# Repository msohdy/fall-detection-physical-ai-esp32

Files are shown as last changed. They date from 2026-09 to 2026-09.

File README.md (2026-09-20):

# Fall Detection & Alert System

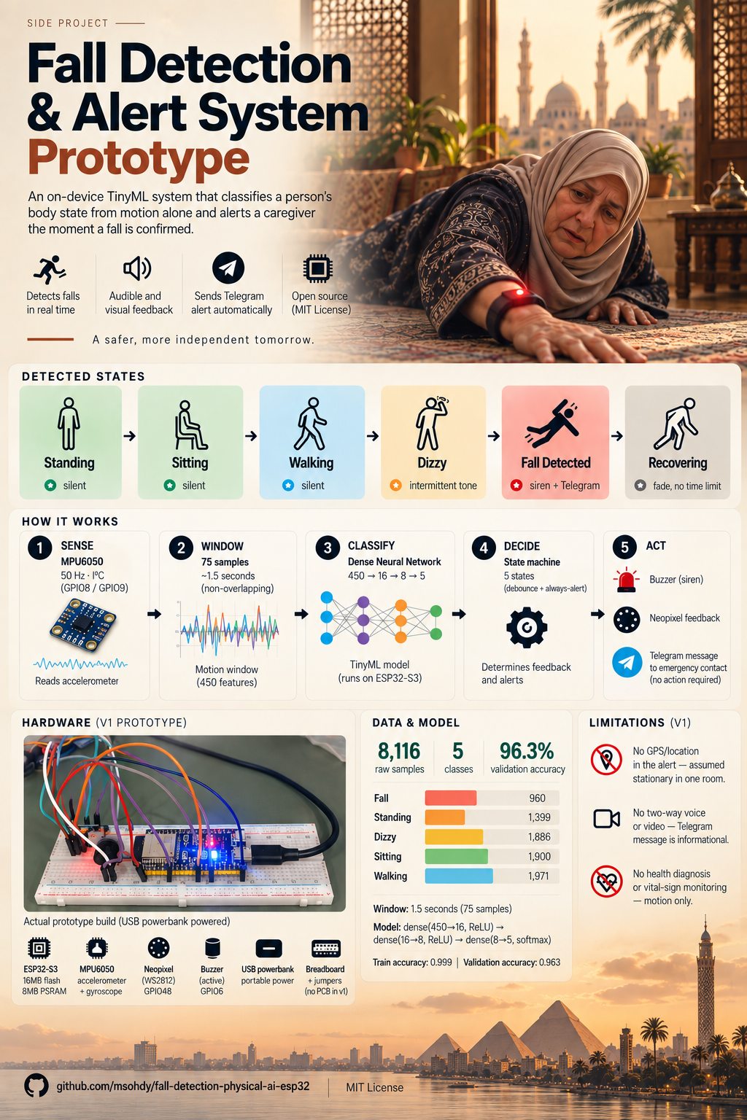
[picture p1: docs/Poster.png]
Fall Detection & Alert System poster


An ESP32-S3 wearable/room device that classifies body state (standing, sitting, walking, dizzy, fall) from MPU6050 motion data using an on-device TinyML model, gives silent per-state Neopixel feedback, sounds a buzzer for concerning states, and sends a Telegram alert to an emergency contact when a fall is confirmed.

**Status:** Phase 6 complete — Phase 7: Testing & Validation in progress. (Phase 6 closed with one small item carried forward: a clean final untethered/battery confirmation run, folded into Phase 7's checklist.)

> This README is being filled in phase by phase as the project is built — see `CLAUDE.md` and `docs/TASKS.md`. Sections below will fill in as each phase completes.

**Repo:** [github.com/msohdy/fall-detection-physical-ai-esp32](https://github.com/msohdy/fall-detection-physical-ai-esp32) · **Project board:** [Fall Detection Build Roadmap](https://github.com/users/msohdy/projects/3)

## Overview

**Problem.** A person living or working alone has no automatic way to signal a fall. Manual alerting (pressing a button, calling out) fails exactly when someone is unconscious or too disoriented to act.

**Goals**

- Classify body state in real time from IMU data: standing, sitting, walking, dizzy, fall.
- Give silent, glanceable feedback (Neopixel color) for every state, so the device isn't alarming during normal activity.
- Escalate audibly only for concerning states (dizzy, fall) — a caregiver should be able to tell severity apart by sound alone.
- On a confirmed fall, notify a remote emergency contact over Telegram without requiring the fallen person to act.
- Require a sustained, confirmed signal before silencing an alarm, to avoid false-clears from a momentary misread.

**Non-goals (v1)**

- No health diagnosis or vital-sign monitoring — the device infers activity state from motion only.
- No GPS/location in the alert (device is assumed stationary within one home/room).
- No two-way voice or video in the alert — the Telegram message is informational, not a call.

**How the built system differs from the original PRD** (full detail in [Firmware Architecture](#firmware-architecture), [Known Limitations](#known-limitations), and `docs/TASKS.md`):

- No TFLite Micro — inference is a hand-rolled forward pass over a custom-trained dense network (Edge Impulse was dropped entirely; see [Training the Model](#training-the-model)).
- Fall confirmation and alerting is a `FALLEN` → `ALARMED` debounce-then-always-alert design, not the PRD's single-frame trigger — a deliberate product decision made during Phase 6 testing, prioritizing "never suppress a real alert" over "never send an extra one."
- v1 is a handheld breadboard prototype (powered by a USB powerbank), not the wearable or room-mounted form factor the PRD assumed — see [Bill of Materials](#bill-of-materials) and the Wiring section's form-factor note.
- "Zero missed falls" is not yet fully met by the trained model (~11.2% of fall samples still confused with "dizzy") — see [Known Limitations](#known-limitations).

## Bill of Materials

- **ESP32-S3 dev board** — generic ESP32-S3-N16R8 board (16MB flash, 8MB PSRAM). Runs the classifier, state machine, and WiFi/Telegram calls. *Not* the official ESP32-S3-USB-OTG devkit that `platformio.ini`'s board ID technically names — see [Build Log](#build-log--decisions).
- **MPU6050 breakout** — standard I²C accelerometer+gyroscope module. Primary sensor, feeds the windowed IMU data the classifier reads.
- **Neopixel LED** — the board's onboard single WS2812 RGB LED (GPIO48), no external strip used. Silent per-state color feedback.
- **Buzzer** — a 3-pin module that turned out to be **active** with no usable signal pin (see [Wiring](#wiring)), controlled by switching its power via GPIO6. Audible escalation for dizzy/fall states.
- **Power source (v1)** — USB powerbank. Portable power for the handheld breadboard prototype.
- **Breadboard + jumper wires** — standard prototyping breadboard, no PCB in v1.

**Not used in this project** (per the original PRD, reserved for a different/future project): camera, DHT11, IR sensor, ultrasonic sensor, fan/relay, servo motor.

*Specific vendor links aren't included yet — these are generic, widely available parts. Sourcing links can be added here later if useful for reproducing the exact build.*

## Wiring

**Diagram tool:** [Fritzing](https://fritzing.org/) (free, open source, breadboard-style diagrams; switched from an initial Wokwi plan once actually building the diagram).

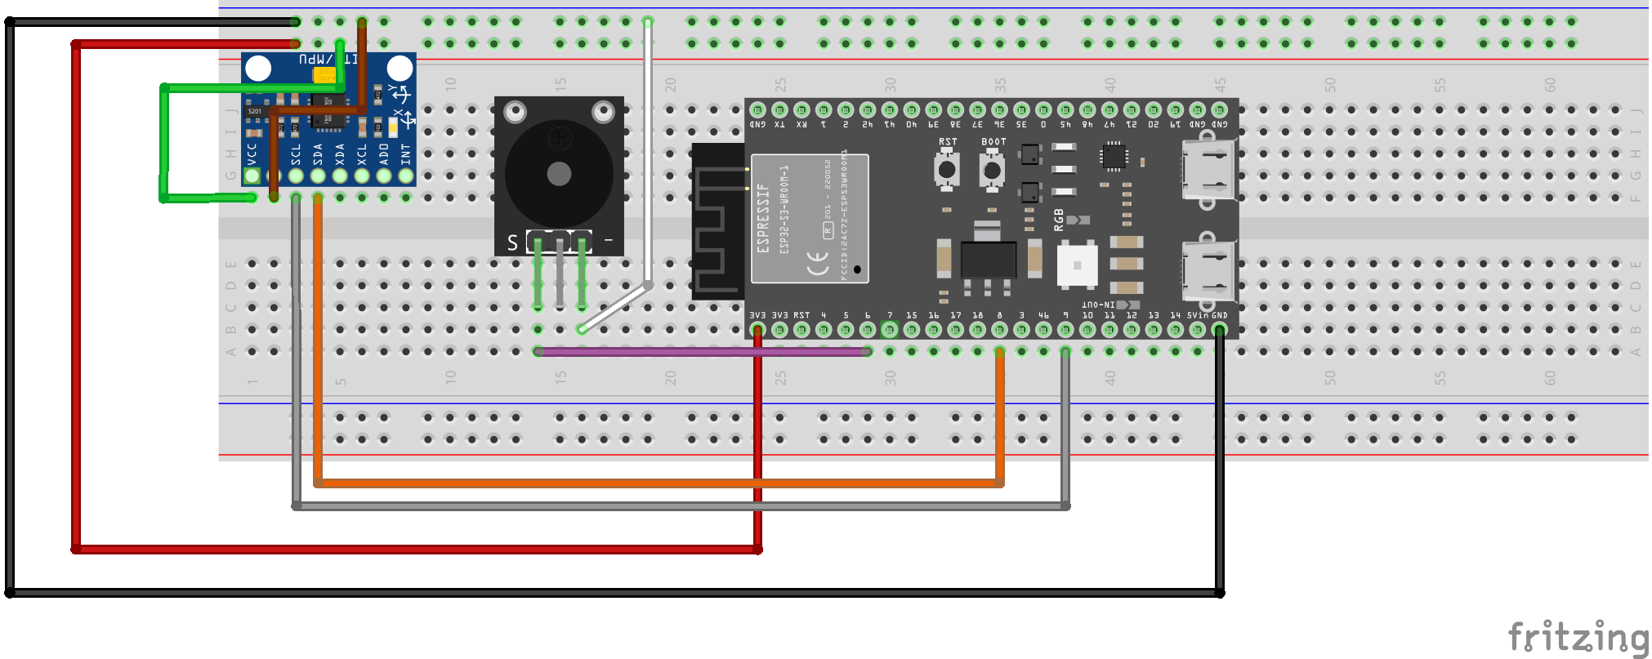
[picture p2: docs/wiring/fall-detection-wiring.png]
Breadboard wiring diagram


Fritzing project source: [`docs/wiring/fall-detection-wiring.fzz`](docs/wiring/fall-detection-wiring.fzz)

**Actual build:**

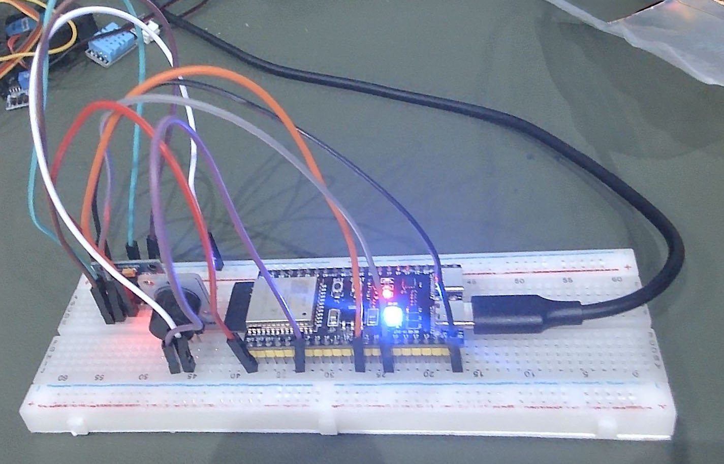
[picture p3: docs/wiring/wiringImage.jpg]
Breadboard photo


**Pin table:**

| Signal | MPU6050 | Neopixel (onboard) | Buzzer (active) |
| --- | --- | --- | --- |
| Power | VCC → 3.3V | onboard, no wiring | + → **GPIO6** (switched power) |
| Ground | GND → GND | onboard | - → GND |
| Data/Signal | SDA → GPIO8 | GPIO48 (onboard) | *(none — see note below)* |
| Clock | SCL → GPIO9 | — | — |

The Neopixel is the board's onboard single WS2812 RGB LED, not an external strip. The buzzer is confirmed **active** with no dedicated signal pin at all — its 3rd pin is unused, and it's controlled by switching power to it directly via GPIO6 (`digitalWrite(HIGH/LOW)`), not `tone()`. See [Build Log / Decisions](#build-log--decisions) for how this was determined.

**Form factor (v1):** breadboard prototype, powered by a USB powerbank — handheld, not worn or room-mounted. No enclosure/form-factor commitment yet; strain relief and wearable-specific concerns are out of scope until a final form factor is chosen.

## Setup

**Firmware toolchain:** [PlatformIO](https://platformio.org/) as a VS Code extension.

- Board: `esp32s3usbotg` in `platformio.ini` (PlatformIO's board ID for Espressif's official ESP32-S3-USB-OTG devkit). The actual hardware is a generic ESP32-S3-N16R8 dev board (confirmed via `esptool flash_id`: ESP32-S3, 16MB quad-I/O flash, 8MB quad PSRAM) — see [Build Log / Decisions](#build-log--decisions).
- Framework: `arduino`
- Confirmed: project builds and uploads over USB (native USB port, shows up as `VID:PID=303A:1001`).

**Before building, set up your own credentials** (the repo never contains real ones):

1. Copy [`include/secrets.h.example`](include/secrets.h.example) to `include/secrets.h` (git-ignored — never commit this file).
2. Fill in `WIFI_SSID` / `WIFI_PASSWORD` for the network the device should join. Note: the ESP32-S3 is **2.4GHz WiFi only** — if using a phone hotspot, make sure it's not set to 5GHz-only (see [Known Limitations](#known-limitations)).
3. Create a Telegram bot via [@BotFather](https://t.me/BotFather) and copy its token into `TELEGRAM_BOT_TOKEN`.
4. Message your new bot once (anything), then visit `https://api.telegram.org/bot<YOUR_TOKEN>/getUpdates` in a browser and copy the numeric `"chat":{"id": ...}` value into `TELEGRAM_CHAT_ID` — not the lookup URL itself, the actual number.

Then build and flash — see [Building & Flashing](#building--flashing) below.

## Data Collection Tooling

**[`tools/serial-data-logger.html`](tools/serial-data-logger.html)** — a self-contained Web Serial page (Chrome/Edge only) for capturing MPU6050 samples to CSV. Built after two Edge Impulse ingestion paths turned out to be dead ends on this setup:

1. `edge-impulse-cli` (for the classic Data Forwarder) failed to install — one dependency needs native compilation via Visual Studio Build Tools, which aren't installed.
2. Edge Impulse Studio's browser-based "Connect a new device" WebSerial flow requires the device firmware to speak Edge Impulse's AT-command protocol — a different thing entirely from plain CSV serial output, and not worth implementing just for data collection.

Connect to the board, log incoming CSV lines to an editable table (delete bad rows individually or in bulk, or reopen an already-saved CSV via **Load CSV**), and export a clean CSV per recording session.

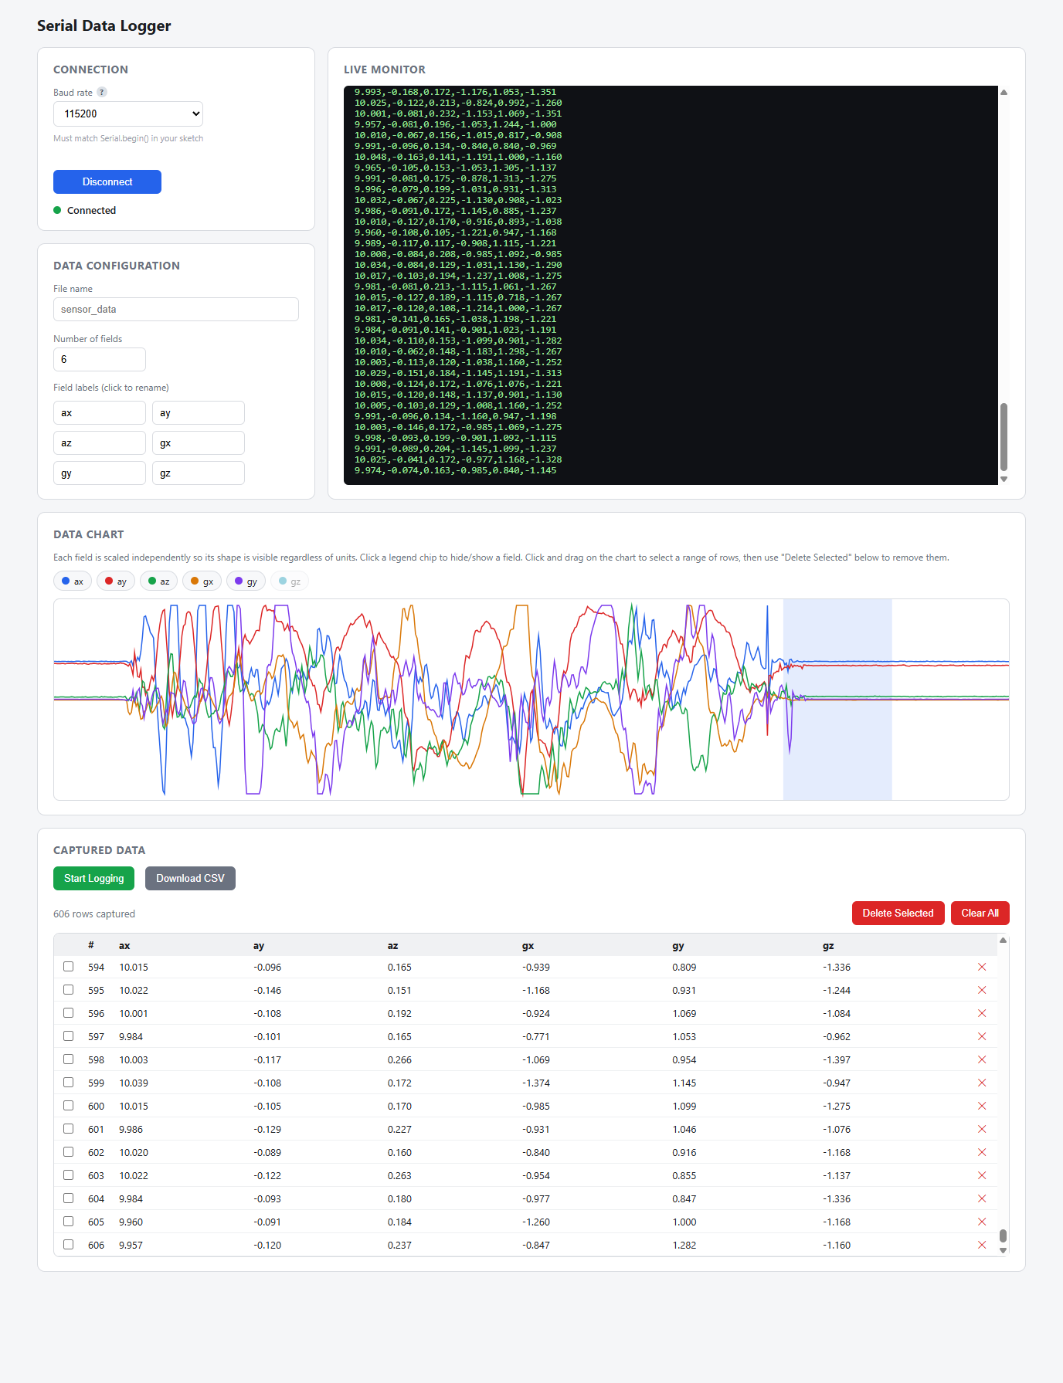
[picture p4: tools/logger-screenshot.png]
Serial Data Logger


See [`tools/README.md`](tools/README.md) for full usage instructions and the data collection + training pipeline diagram.

## Training the Model

Edge Impulse was dropped entirely as the training platform too (not just the data-connection method above) — see [Build Log / Decisions](#build-log--decisions). Instead: **[`tools/tinyml-trainer.html`](tools/tinyml-trainer.html)**, a self-contained TensorFlow.js page that trains a small dense-network classifier client-side and exports a plain C header for firmware.

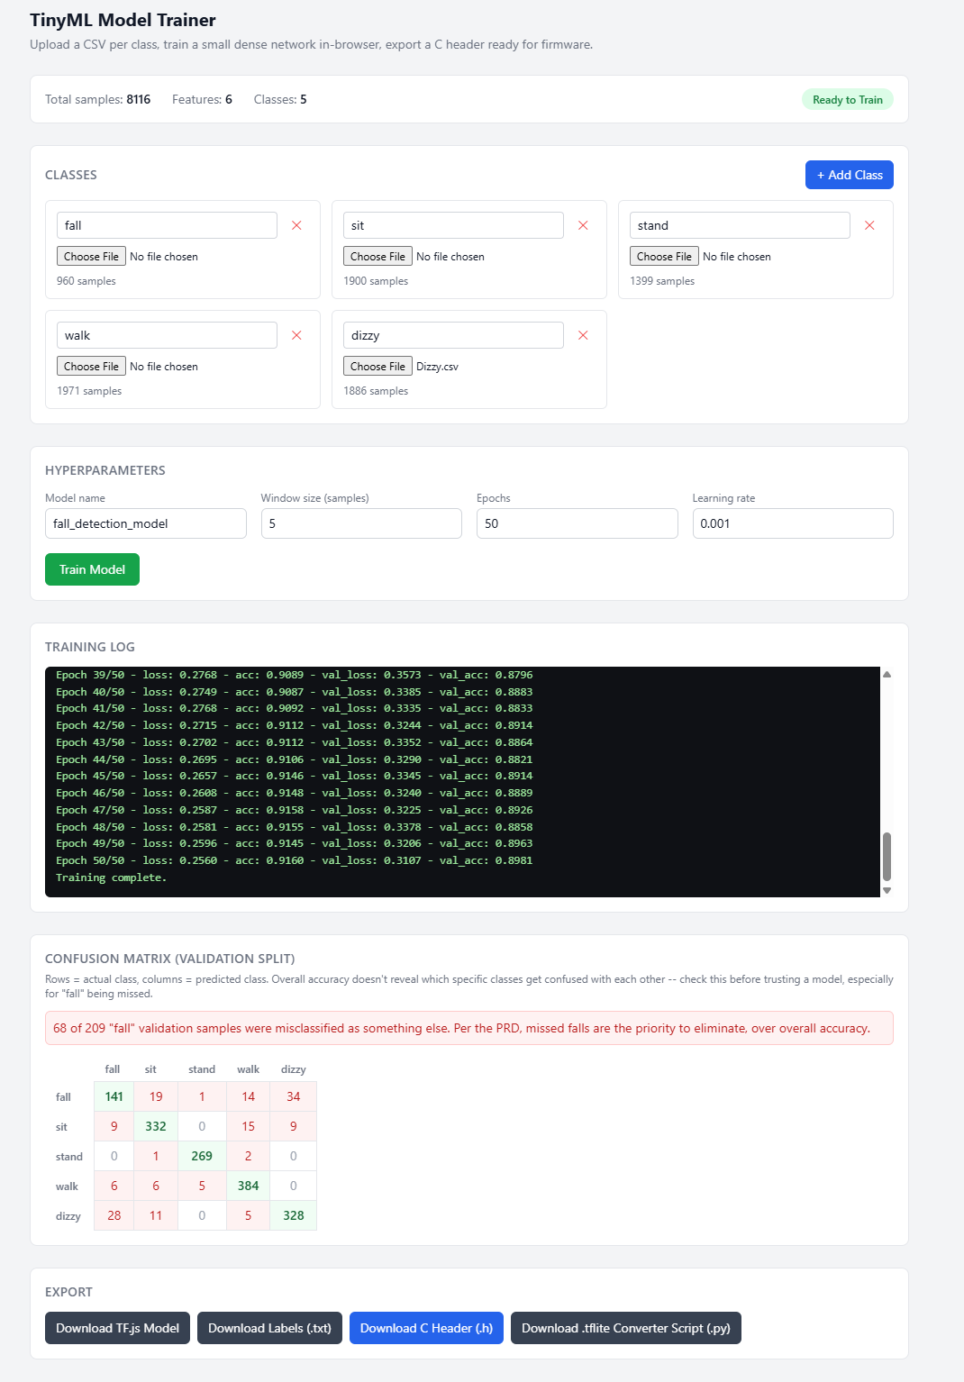
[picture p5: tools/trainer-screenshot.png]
TinyML Model Trainer


**Dataset:** 8116 raw samples across 5 classes (fall 960, sit 1900, stand 1399, walk 1971, dizzy 1886), collected handheld (see Wiring's form-factor note) via `serial-data-logger.html`.

**Model:** `dense(16, relu) → dense(8, relu) → dense(5, softmax)`, trained on windowed raw accel+gyro samples (no DSP/spectral feature extraction). Final: window size 75 samples (~1.5s at 50Hz), 50 epochs, learning rate 0.001, train accuracy 0.999, validation accuracy 0.963.

**Window size mattered a lot.** Started at window=5 (100ms) — far shorter than the PRD's suggested ~1-2s — and it showed:

| Window size | Duration @ 50Hz | Overall val accuracy | Fall samples missed |
| --- | --- | --- | --- |
| 5 | 0.1s | ~0.87 | 68/209 (32.5%) |
| 50 | 1.0s | 0.958 | 39/191 (20.4%) |
| 75 | 1.5s | 0.963 | 23/205 (11.2%) — accepted for v1 |

**Known limitation:** the PRD's "zero missed falls" bar is not fully met — 11.2% of fall validation samples are still confused with "dizzy," which is more likely a data-realism issue (handheld mimicked falls vs. a real worn fall's sharper signature) than something further hyperparameter tuning alone would fix. See [Known Limitations](#known-limitations).

Full model header: [`include/fall_detection_model_data.h`](include/fall_detection_model_data.h). See [`tools/README.md`](tools/README.md) for the trainer's usage instructions and a real bug (a `validationSplit` shuffling gotcha) worth knowing about if you extend this tool.

## Firmware Architecture

**Deviation from the PRD:** no TFLite Micro. Since training moved to a custom in-browser trainer (above) that exports raw float weight/bias arrays instead of a `.tflite` file, the firmware does inference by hand instead of via a TFLite Micro runtime.

| Module | Files | Responsibility |
| --- | --- | --- |
| MPU6050 driver | `mpu6050.h/.cpp` | Raw I2C register reads (same approach as the Phase 4 data-forwarder sketch), scaled to match training data exactly |
| Model inference | `model_inference.h/.cpp` | Hand-rolled `dense(450→16, ReLU) → dense(16→8, ReLU) → dense(8→5) → argmax` forward pass over `fall_detection_model_data.h` |
| Neopixel driver | `neopixel_driver.h/.cpp` | `VisualState` enum; steady colors for standing/sitting/walking/dizzy, non-blocking pulse/fade animation for alarmed/recovering |
| Buzzer driver | `buzzer_driver.h/.cpp` | `BuzzerState` enum; distinct non-blocking on/off beep *patterns* per state (this buzzer can't vary pitch — see Wiring section) |
| State machine | `state_machine.h/.cpp` | NORMAL/DIZZY/FALLEN/ALARMED/RECOVERING transitions, using string comparison against model labels (not hardcoded indices) |
| Telegram | `telegram.h/.cpp` | HTTPS GET to the Bot API, run entirely on its own FreeRTOS task (see below) so a slow/retrying send can never stall sensor sampling or classification |

**Classification runs on a fresh, non-overlapping ~1.5s window per cycle**, not continuously — see [Known Limitations](#known-limitations) for why continuous classification made false alarms dramatically worse.

**Fall confirmation and alerting (deviation from the original single-fall-triggers-alert design, decided during Phase 6 testing):** a fall reading enters a `FALLEN` state with a short ~4s debounce (filters a single noisy frame, nothing more; the timer is set once on the first fall reading and never reset, so it can't stretch out on a prolonged settling motion), after which the Telegram alert **always** fires — never conditionally on whether the person seems to be recovering. An earlier version waited up to 20 seconds to decide whether to alert at all, canceling quietly if the person got up in time; this was built, tested, and rejected: missing a real fall is worse than an occasional extra alert. Recovery is fully decoupled from the alert and has no time limit — after `ALARMED`, sustained non-fall readings (stand, sit, walk, or dizzy — "sit" was excluded until Phase 6 field testing showed the model classifies a lot of real post-fall movement as "sit," which left the alarm stuck) move to `RECOVERING` then `NORMAL` and send a "Resolved" message. The buzzer escalates from an intermittent siren during the debounce to a continuous tone once confirmed.

**Telegram sending runs on its own FreeRTOS task** (`xTaskCreatePinnedToCore`, pinned to core 0, separate from Arduino's `loop()` on core 1), not inline in the state machine. `state_machine.cpp` only calls fire-and-forget `telegramSendFallAlert()`/`telegramSendResolved()`; the background task owns all retry/backoff/delivery. This was a real bug fix, not just cleanup: the blocking HTTPS/TLS call was originally invoked directly from `stateMachineUpdate()`, so while a send was in flight (which can take seconds, especially retrying on a flaky connection) the *entire main loop froze* — no new IMU samples, no new classifications, frozen animations — which looked exactly like the state machine being "stuck," because it genuinely was. Message delivery also persists across state transitions: a pending alert keeps retrying until it actually succeeds no matter what the state machine does in the meantime (e.g. a quick recovery before WiFi reconnects no longer silently drops the alert).

**Confirmed working end-to-end on real hardware, twice in a row (once before the async-task fix, once after)**: fall → alert sent → recovered → resolved message sent → second fall → alert sent again, with real Telegram messages received on a phone every time, and — after the async fix — the classification heartbeat confirmed never skipping a beat even while a send was actively in flight or retrying.

See `docs/TASKS.md` (Phase 5 and Phase 6) for the full list of deviations and bugs found/fixed along the way — a linker "multiple definition" gotcha from the generated model header, the false-alarm classification-rate fix, a build-blocking typo in `secrets.h`, a WiFi-silently-drops-and-never-reconnects bug, a WiFi reconnect throttle fighting itself, a router-side rate-limit block, a phone hotspot's 5GHz band being invisible to the 2.4GHz-only ESP32-S3, a `secrets.h` edit not triggering a relink, and the fall-confirmation/async-task fixes above.

## Building & Flashing

**Toolchain:** PlatformIO. Platform `espressif32 @ 7.0.1`, `framework-arduinoespressif32 @ 3.20017.241212+sha.dcc1105b`, `tool-esptoolpy @ 4.11.0`, board `esp32s3usbotg`.

```bash
pio run                                    # compile
pio device list                            # find the serial port
pio run --target upload --upload-port <port>
pio device monitor --port <port> --baud 115200
```

**Gotcha — this board does not auto-reset into the bootloader.** `pio run --target upload` fails with `A fatal error occurred: Failed to connect to ESP32-S3: No serial data received.` unless you manually enter bootloader mode first: hold **BOOT**, then press-and-release **RESET** (or unplug/replug USB) while still holding BOOT. The board re-enumerates under a **different port** while in bootloader mode (e.g. `/dev/cu.usbmodem101` instead of `/dev/cu.usbmodem30EDA0A8ADE01`), showing as "USB JTAG/serial debug unit" instead of "Espressif ESP32-S3-USB-OTG" — upload to that port. It hard-resets back to the original port/name automatically once the upload finishes.

No serial output existed at all before Phase 6 bring-up — `main.cpp`, `state_machine.cpp`, and `telegram.cpp` now log a per-cycle `[cycle] predicted=<label> wifi=<connected|disconnected>` heartbeat plus `[state]`/`[wifi]`/`[telegram]` transition and send-result lines, which is what made the WiFi/Telegram bugs above diagnosable instead of guessed at.

## Testing & Validation

*(Full writeup pending — Phase 7 in progress. Two results already in from Phase 6's bug-fixing work:)*

- **WiFi-down path:** confirmed the local alarm (Neopixel + siren) fires regardless of WiFi state, and the classification loop never stalls while WiFi is down or a Telegram send is actively in flight/retrying (verified once Telegram sending moved to its own FreeRTOS task — see [Firmware Architecture](#firmware-architecture)).
- **Relapse path:** observed live (`RECOVERING -> ALARMED` on a fresh fall reading), with a fresh alert sent successfully.

Still open: classifier accuracy re-check on-device, end-to-end latency logged across multiple trials, systematic zero-missed-falls testing, recovery false-clear resistance, and a final clean untethered confirmation run (carried over from Phase 6). See `docs/TASKS.md` Phase 7 for the full checklist.

## Known Limitations

*(Full writeup during Phase 8 — noting the significant one early since it's directly measured, not speculative.)*

- **Fall detection does not fully meet "zero missed falls" yet.** The trained model misses ~11.2% of fall validation samples (23/205), almost all confused with "dizzy." This is very likely tied to the handheld (not worn) form factor — a real fall experienced by a worn device has a sharper acceleration/rotation signature than a handheld mimicked fall motion, making "fall" and "dizzy" genuinely harder to tell apart in this dataset. Revisit with a wearable form factor and/or more/cleaner fall data.
- **Occasional false alarms are expected, by design trade-off.** The model also has a small non-fall→fall misclassification rate (~1.2%, mostly dizzy→fall). Firmware classifies once per ~1.5s window (not continuously), which keeps this down to roughly one false alarm every couple of minutes at rest — acceptable per the PRD's explicit priority (missed falls matter more than false positives), but worth knowing before real-world deployment. See Phase 5 notes in `docs/TASKS.md` for the math on why continuous (sliding-window) classification made this dramatically worse and was reverted.
- **The 4-second fall-confirmation debounce doesn't fix the model's fall↔dizzy confusion above, but it does mean the alert no longer depends on correctly detecting recovery.** Earlier in Phase 6, the alert was briefly designed to wait and see whether the person recovered before deciding whether to alert at all — that approach would have compounded the model's known weaknesses into missed alerts. The current design alerts unconditionally on a confirmed fall, so those model/recovery-detection issues can no longer suppress a real alert — only delay the unrelated "Resolved" message.
- **WiFi connect time is inconsistent and occasionally very slow (observed anywhere from ~5s to 90+s) after a cold boot.** Root cause not fully pinned down — likely a mix of normal WPA2/DHCP variance and, in a couple of cases, a router-side anti-flood block triggered by an earlier firmware bug's overly aggressive reconnect attempts (since fixed). Message delivery is resilient to this regardless (it retries indefinitely, independent of the state machine), but a very slow connect does mean a longer real-world delay before the alert actually reaches a phone. Worth further investigation if it recurs without an obvious cause.

## Build Log / Decisions

*(A running record of meaningful choices and deviations from the original plan, added as they happen — see `CLAUDE.md`.)*

- **License:** MIT, chosen over Apache-2.0 for simplicity (no patent-grant needs expected for a hobbyist hardware project).
- **PlatformIO board ID:** `platformio.ini` uses `board = esp32s3usbotg`, which is PlatformIO's ID for Espressif's *official* ESP32-S3-USB-OTG devkit (LCD + 4 physical buttons). The actual hardware is a generic ESP32-S3-N16R8 dev board with none of that — confirmed by asking the chip directly via `esptool flash_id`: ESP32-S3, 16MB quad-I/O flash, 8MB quad PSRAM. This board ID was kept intentionally despite the mismatch; it builds and uploads fine, but its pin macros won't match this hardware, so **Phase 3 wiring will need pins set explicitly in `include/pins.h` rather than relying on board-default pin names**.
- **Serial-over-USB gotcha:** this board has one native USB port (no separate CH340/CP2102 UART bridge), enumerating as `VID:PID=303A:1001`. Arduino's `Serial` doesn't route through that port by default — without `-DARDUINO_USB_CDC_ON_BOOT=1` in `build_flags`, `Serial.print()` silently goes to unused physical UART0 pins instead. This flag is now set in `platformio.ini` (added once `main.cpp` needed serial output for I2C bring-up testing).
- **GitHub Issues/Projects granularity:** one GitHub Issue was created per phase (not per individual task) and attached to a matching milestone, so the [Project board](https://github.com/users/msohdy/projects/3) stays readable. `docs/TASKS.md` remains the source of truth for task-level detail — each phase issue links back to its section there.
- **Secrets:** moved from the Phase 1 `.env` notes into a proper git-ignored `include/secrets.h` (with `secrets.h.example` committed as the template) in Phase 5. The `.env`'s saved "chat ID" turned out to actually be the `getUpdates` *lookup URL*, not the real numeric chat ID — had to message the bot and call that URL for real to get the actual ID.
- **Telegram HTTPS uses `WiFiClientSecure::setInsecure()`** (no certificate pinning) — a common simplification for a hobbyist project, at the cost of no protection against a MITM on the local network. A future hardening pass could embed Telegram's root CA certificate instead.
- **Deferred (by choice, not forgotten):** `CODEOWNERS`/PR-review notes and GitHub Discussions — both explicitly pushed to closer to Phase 7/8 when the project has outside contributors.
- **Buzzer confirmed active** by direct test: connecting VCC to 3.3V and GND with the 3rd pin left unwired produced a steady, continuous tone — meaning it has its own internal driver circuit. This corrects an initial guess of "passive" based on an old sample sketch that used `tone()` with varying frequencies; that sketch apparently doesn't match this actual buzzer.
- **Buzzer has no logic-level control pin at all** — its 3rd pin turned out to be unused (it buzzed with just VCC+GND wired). Control instead works by switching **power** to the buzzer: the wire originally planned for a fixed 3.3V rail goes to **GPIO6** instead, which sources power directly; GND stays on GND; the 3rd/mid pin is left disconnected. Confirmed working via `digitalWrite(GPIO6, HIGH/LOW)`. Since an active buzzer also can't vary pitch, the PRD's "distinct tone per state" requirement will need to become distinct on/off beep *patterns* instead (Phase 5). Driving the buzzer directly off a GPIO (no transistor) works for now but may need revisiting if current draw proves too high for the pin.
- **I2C pins set explicitly rather than relying on board defaults**, since `platformio.ini`'s board ID doesn't exactly match the physical hardware (see the board-ID note above) — GPIO8 (SDA) / GPIO9 (SCL), which happen to match the Arduino-ESP32 core's own `Wire.begin()` defaults on ESP32-S3 anyway.
- **Edge Impulse dropped entirely, not just its data-connection method.** After building `serial-data-logger.html` to work around two Edge Impulse ingestion dead-ends, training itself was also moved off Edge Impulse — a 5-class classifier on raw windowed IMU data doesn't need Edge Impulse's DSP/Spectral Analysis blocks, and a fully local pipeline keeps the project reproducible without an external account. Built `tools/tinyml-trainer.html` (TensorFlow.js, in-browser) instead, exporting a plain C header with raw float weight/bias arrays. This means **Phase 5 firmware will implement inference by hand** (a small forward pass over the exported arrays) rather than integrating the TFLite Micro runtime the PRD originally assumed.
- **Found and fixed a real bug in the training tool**: early runs showed validation accuracy stuck low (~0.3-0.5) and unstable while training accuracy climbed normally — not standard overfitting, but because the windowed dataset was built one class at a time, and TensorFlow.js's `validationSplit` carves its slice off the *end* of the array before any shuffling. The validation set was almost entirely just the last class or two. Fixed by shuffling the windowed samples across classes before training.
- **Window size tuned from 5 to 75 samples** after discovering the initial default (100ms at 50Hz) was far too short to characterize a fall's shape, causing heavy confusion with "dizzy." See [Training the Model](#training-the-model) for the full tuning table and the resulting known limitation.
- **Generated model header must only be included from one `.cpp` file.** `fall_detection_model_data.h` defines `LABELS[]` and the weight/bias arrays without `extern`, so including it from more than one file causes a linker "multiple definition" error (and would otherwise silently duplicate ~160KB of flash per file that includes it). Firmware confines it to `src/model_inference.cpp`; everything else goes through `model_inference.h`, which mirrors the model's dimension macros with a `static_assert` guard so a future retrain with different dimensions fails the build instead of silently misbehaving.
- **Classification runs on a fresh window per cycle, not a continuous sliding window.** An early firmware version classified on every new IMU sample (~50Hz sliding window) for lower latency, but combined with the model's small non-fall→fall misclassification rate (~1.2%, mostly dizzy→fall), that compounded into false ALARMED triggers roughly every few seconds even at rest. Reverted to a fresh, non-overlapping window per classification (~0.67/sec) — this also matches how the model was actually validated (independent windows) — bringing false alarms down to roughly once every couple of minutes. See [Known Limitations](#known-limitations).
- **Real bug: WiFi silently drops and never reconnects on its own, which was the actual cause of "a second fall's Telegram alert never sends."** Live testing showed a first fall alert send fine, then a second fall right after produce no alert at all with no visible error. Root cause (found only after adding serial logging that hadn't existed before): WiFi disconnected and stayed disconnected for 25+ seconds with zero recovery attempts, despite `WiFi.setAutoReconnect(true)`. Fixed with `WiFi.setSleep(false)` (disables ESP32 modem sleep, a known cause of exactly this) plus an active, throttled reconnect loop (`telegramTick()` in `telegram.cpp`, retrying `WiFi.begin()` at most once per 5s) called every ~20ms from the main sampling loop. Confirmed fixed end-to-end: two falls in a row now both alert successfully.
- **Real bug: repeated failed Telegram sends risked hanging the device.** One test showed a failed send followed by the serial heartbeat itself going silent — consistent with a second back-to-back TLS handshake (a fresh `WiFiClientSecure`/`HTTPClient` per attempt) hanging rather than failing fast. Fixed by throttling retry attempts to at most once per 5 seconds instead of every ~1.5s classification cycle.
- **State machine redesigned around a "did they get up" question — a product decision made mid-Phase-6 testing, deviation from the original single-fall-triggers-alert design.** A fall now enters a `FALLEN` state with a short ~4-second debounce (filters a single noisy frame, nothing more) before confirming. **The Telegram alert always fires once a fall is confirmed — never conditionally on whether the person seems to recover.** An earlier version of this redesign waited up to 20 seconds to decide whether to alert at all, canceling quietly (no message ever sent) if the person got up in time; this was built, tested, and explicitly rejected, since missing a real fall is worse than an occasional extra alert, and gating the alert on the same recovery-detection logic that already had a known bug (the ALARMED→RECOVERING "sit exclusion" issue noted in Phase 5) was too risky. Recovery afterward is unchanged and unlimited in time: sustained stand/dizzy/walk readings move ALARMED → RECOVERING → NORMAL and send the "Resolved" message.
- **This board does not auto-reset into the bootloader.** Every upload requires manually holding BOOT and pressing/releasing RESET (or unplugging/replugging USB) first — esptool's normal auto-reset sequence fails with "No serial data received" otherwise. See [Building & Flashing](#building--flashing).
- **Real bug: a pending alert could be silently abandoned if the state moved on before WiFi came up.** The retry logic originally lived inside the `ALARMED` switch case, so if the person recovered before WiFi ever reconnected, the send attempts just stopped — not delayed, lost. Found via a power-bank test where WiFi took 20-35s to reconnect after a cold boot. Fixed by hoisting message delivery out of the state switch entirely: a pending alert or resolved message now retries every cycle regardless of `AppState`, until it actually succeeds.
- **Real bug: the fall-confirmation debounce could stretch to 15-20+ seconds instead of ~4s.** The debounce timer restarted on every repeated "fall" classification (meant for a genuine relapse), but a single real fall's settling motion can span several classification windows in a row, each one pushing the timer further out. Fixed by setting the timer once on the first fall reading and never resetting it within the same episode.
- **Real bug: WiFi's own reconnect logic was fighting itself, stretching a normal ~5-10s connect out to 60-90+ seconds.** Calling `WiFi.begin()` again every 5s while disconnected can abort and restart an in-progress handshake before it finishes. Fixed by raising the throttle to 15s.
- **Discovered, not a firmware bug: a home router can temporarily rate-limit/block a device that reassociates too aggressively.** Hit this after the bug above had been live for a while — WiFi stopped connecting entirely, then started working again after enough time passed. Likely a router-side anti-flood defense. Not fixable from firmware; power-cycling the router or waiting it out cleared it.
- **Discovered, not a firmware bug: a phone hotspot can default to 5GHz, invisible to the ESP32-S3's 2.4GHz-only radio.** Worth checking a hotspot's band/"maximize compatibility" setting before assuming a connectivity issue is a firmware bug.
- **Real bug (the actual root cause of "stuck" states and the multi-second alert delay): the Telegram send blocked the entire main loop.** See [Firmware Architecture](#firmware-architecture) above for the full explanation and fix (moving Telegram sending to its own FreeRTOS task).
- **Recovery criteria broadened to include "sit"** in `isRecoverySign()` (now "any non-fall reading"), reverting the Phase 5 exclusion that caused the ALARMED-stuck bug. Safe now that alerting no longer depends on recovery detection succeeding.
- **Added a purple-flash-x3 Neopixel indicator on WiFi connect**, non-blocking, so WiFi status is visible during untethered/battery field testing without a serial monitor attached.

## License

MIT — see [`LICENSE`](LICENSE).

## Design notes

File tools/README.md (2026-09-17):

# tools/

## mpu6050-data-forwarder.cpp

The firmware sketch used to collect all Phase 4 training data — streams `accX,accY,accZ,gyrX,gyrY,gyrZ` over serial at ~50Hz for `serial-data-logger.html` to capture. Archived here once Phase 5 replaced `src/main.cpp` with the real firmware. PlatformIO only compiles `src/`, so to reuse this (e.g. to collect more training data later), copy it into `src/main.cpp`, rebuild, and reflash.

## serial-data-logger.html

A self-contained Web Serial page (Chrome/Edge only) for capturing MPU6050 CSV data during Phase 4 data collection. No build step, no server — just open the file directly in a Chromium browser.

Serial Data Logger

### Why this exists

Two Edge Impulse ingestion paths turned out to be dead ends for this project's setup:

1. `edge-impulse-cli` (for the classic Data Forwarder) failed to install — one dependency needs native compilation via Visual Studio Build Tools, which weren't installed.
2. Edge Impulse Studio's browser-based "Connect a new device" WebSerial flow requires the device firmware to speak Edge Impulse's AT-command protocol — a different thing entirely from the plain CSV our sketch streams.

So data is captured locally with this tool instead, cleaned up, and exported as plain CSVs. (Edge Impulse was later dropped entirely — see `tinyml-trainer.html` below — but this tool's job, turning a live serial stream into a clean labeled CSV, stayed the same either way.)

### How to use it

1. Open `serial-data-logger.html` directly in Chrome or Edge.
2. Flash the board with the current data-forwarder sketch (`src/main.cpp`), which streams `accX,accY,accZ,gyrX,gyrY,gyrZ` at ~50Hz.
3. Click **Connect Serial**, pick the board's port, confirm baud rate matches the sketch (115200 by default — hover the `?` next to the field if unsure what this means).
4. Fields default to 6 (`ax, ay, az, gx, gy, gz`) matching the sketch — rename them if your sketch's columns differ.
5. Set a **File Name** for the session (e.g. `standing_01`).
6. Click **Start Logging**, perform the activity, click **Stop Logging**.
7. Use the **Data Chart** to spot and clean up bad segments: click a legend chip to isolate a field, then click-and-drag over a range you want gone (e.g. the calm/rest periods between repeated fall attempts) — this selects those rows, which you then remove with **Delete Selected**.
8. Click **Download CSV** and save it into `data/raw/` (git-ignored — see `data/README.md`).
9. Repeat per class/session.
10. To revisit an already-saved recording for a second cleanup pass, use **Load CSV** to reopen it in the table/chart.

## tinyml-trainer.html

A self-contained TensorFlow.js page (any modern browser, internet access needed once for the CDN scripts) that trains a small dense-network classifier on the CSVs above, entirely client-side, and exports a plain C header ready to drop into firmware.

TinyML Model Trainer

### Why this exists

Edge Impulse was dropped as the training platform too, not just the data-connection method. A 5-class classifier on raw windowed IMU samples doesn't need Edge Impulse's DSP/Spectral Analysis blocks, and training locally keeps the whole pipeline reproducible without an external account. The exported model is a set of raw float weight/bias arrays for a `dense(16) → dense(8) → dense(numClasses)` network — no TFLite Micro runtime needed, just a hand-rolled forward pass in firmware (Phase 5).

### How to use it

1. Open `tinyml-trainer.html` directly in a browser.
2. For each class, click **+ Add Class**, name it, and upload its CSV from `data/raw/` (the header row is auto-detected and skipped).
3. All classes must share the same number of feature columns — the tool validates this and shows an error otherwise.
4. Set **Window size** — this is the number of consecutive samples flattened into one training example. **This matters a lot**: too short a window can't capture what an event like a fall actually looks like. At 50Hz, a window of 75 samples ≈ 1.5 seconds, matching the PRD's suggested window range. See `docs/TASKS.md` (Phase 4) for the full tuning story — window size 5 (100ms) performed far worse than 75.
5. Set **Epochs**, **Learning rate**, and a **Model name**, then click **Train Model**. Training runs entirely in your browser; the log streams live loss/accuracy per epoch.
6. Check the **Confusion Matrix** that appears after training — it's computed on a held-out validation split and specifically flags in red if any "fall" samples were misclassified, since overall accuracy can look good while still missing falls (the one thing this project can't afford, per the PRD).
7. Export: **C Header (.h)** is the one that matters for firmware — save it as `include/fall_detection_model_data.h`. The other exports (TF.js model, labels.txt, `.tflite` Python converter script) are there if you want to keep training or convert to TFLite Micro instead later.

### A real bug this tool taught us

Early training runs showed validation accuracy stuck around 0.3–0.5 and bouncing around while training accuracy climbed normally to ~0.84 — it looked like classic overfitting, but the actual cause was more specific: the windowed dataset was built one class at a time (all "fall" windows, then all "sit" windows, etc.), and TensorFlow.js's `validationSplit` carves its slice off the *end* of that array *before* any shuffling happens each epoch. The validation set ended up being almost entirely just the last class or two — not a representative sample. The fix was shuffling the windowed samples across all classes before calling `model.fit()`. Worth knowing if you extend this tool or write something similar: `validationSplit` is not a substitute for shuffling your own data first.

### Data collection & training pipeline

```mermaid
flowchart LR
    FW[ESP32-S3 firmware<br/>streams accX..gyrZ over USB] --> LOG[serial-data-logger.html<br/>Web Serial capture]
    LOG --> CHART[Data Chart<br/>drag-select to clean up<br/>rest/noise segments]
    CHART --> CSV[Download CSV<br/>one file per class/session]
    CSV --> RAW[data/raw/<br/>git-ignored]
    RAW --> TRAIN[tinyml-trainer.html<br/>windowing + dense NN training]
    TRAIN --> CONF[Confusion matrix check<br/>especially fall misses]
    CONF --> HEADER[C header export]
    HEADER --> INCLUDE[include/fall_detection_model_data.h]
    INCLUDE --> FW2[Phase 5 firmware<br/>hand-rolled inference]
```

One continuous recording = one class label, so classes are never mixed within a single CSV. See `docs/TASKS.md` (Phase 4) for the per-class collection notes, including how "fall" is captured as repeated attempts in one session and then cleaned up via the chart's drag-select, and the full window-size tuning results.

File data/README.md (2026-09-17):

# data/

Small, representative sample IMU captures only (a few examples per class,
for anyone browsing the repo to see the raw data shape). The full training
dataset lives in Edge Impulse (see Phase 4) — this folder is not a mirror
of it.

Raw per-session recordings from `tools/serial-data-logger.html` go in
`data/raw/`, which is git-ignored — copy 1-2 representative CSVs per
class here (in `data/`, not `data/raw/`) instead.

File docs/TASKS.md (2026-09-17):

# Fall Detection System — Build & Open-Source Task List

2026-09-17 · @u_Gd73xkkFmo9snIgr0fdFzg

## Overview

This is the execution checklist for the Fall Detection & Alert System PRD: a room/wearable ESP32-S3 device that classifies body state from an MPU6050 and sends a Telegram alert on a confirmed fall. Work through the seven phases in order — each one hands off what the next needs (wiring before firmware, trained model before flashing, working device before writing it up).

Each task below is a checkbox. As you close a task, capture what you'd tell someone reproducing this from scratch (settings used, gotchas hit, screenshots to take) — that running log becomes the open-source README, so document as you go rather than after the fact.

**Phases**

1. Project setup (PlatformIO + repo scaffolding)
2. GitHub project setup (repo, Issues, Projects board, milestones)
3. Wiring (diagram tools + physical build)
4. TinyML data collection & training (Edge Impulse)
5. Firmware coding & pin configuration
6. Build, flash & upload
7. Testing & validation
8. Documentation & open-source release

## Phase 1 — Project Setup

- [x] Install [PlatformIO](https://platformio.org/) as a VS Code extension (free, open source) — install [VS Code](https://code.visualstudio.com/) first if you don't have it, then add the PlatformIO IDE extension from the marketplace
- [x] Create a new PlatformIO project — **deviation:** created via the PlatformIO "New Project" wizard with `board = esp32s3usbotg`, framework = `arduino`. Note this is technically Espressif's official ESP32-S3-USB-OTG devkit board *definition* (LCD + 4 buttons), not an exact match for the actual hardware (a generic ESP32-S3-N16R8 dev board, confirmed via `esptool flash_id`: ESP32-S3, 16MB quad flash, 8MB quad PSRAM). Kept as-is by choice — pin-mapping mismatches from this will need attention once Phase 3 wiring starts referencing board-specific pin macros.
- [x] Confirm the board builds and uploads a blank sketch before touching sensors — build + upload over USB confirmed working (COM8, native USB on `VID:PID=303A:1001`). Serial output verification was skipped for now (the wizard's default `main.cpp` doesn't call `Serial.begin()`/print anything) — revisit once `main.cpp` actually needs serial output. Note: this board's native USB port required boot to actually route Arduino's `Serial` there in earlier testing; if serial output looks silent later, check whether `-DARDUINO_USB_CDC_ON_BOOT=1` is needed in `build_flags`.
- [x] Set up the repo structure for open-sourcing from day one:
  - `/src` — firmware (`main.cpp`, state machine, drivers)
  - `/include` — headers (pin map, config constants)
  - `/lib` — the Edge Impulse exported library (added in Phase 3)
  - `/docs` — wiring diagrams, photos, this task list exported as the README
  - `/data` — sample IMU captures (small representative samples only — raw training data usually stays out of git; note where the full dataset lives)
  - `/test` — added automatically by the PlatformIO wizard (PlatformIO Unity test runner scaffold); not in the original plan but harmless, left in place
  - `platformio.ini` — board, framework, and library dependencies pinned to versions
- [x] Add a `.gitignore` for PlatformIO (`.pio/`, `.vscode/` build artifacts) — used PlatformIO wizard's auto-generated `.gitignore`
- [x] Initialize the git repo and pick an open-source license (MIT or Apache-2.0 are the common defaults for hobbyist hardware projects) — **chose MIT**, copyright line uses the `msohdy` git identity rather than a legal name (fine for an open-source hobby project); added `LICENSE` and a stub `README.md`
- [x] Create a Telegram bot via [@BotFather](https://t.me/BotFather) and note the bot token + your chat ID — done; token/chat ID currently saved in a local `.env` (now git-ignored) as personal notes. **Note:** `.env` is not read by the firmware — Arduino/PlatformIO can't load it at compile or run time without custom build scripting. Per the PRD, the actual values will move into `include/secrets.h` (a git-ignored C++ header, with a `secrets.h.example` template committed) when Telegram integration is coded in Phase 5.

## Phase 2 — GitHub Project Setup

- [x] Create the GitHub repo (public, since this is going open source) and push the local repo from Phase 1 as the initial commit — created via `gh repo create`: [msohdy/fall-detection-physical-ai-esp32](https://github.com/msohdy/fall-detection-physical-ai-esp32)
- [x] Add repo topics/tags for discoverability (`esp32`, `tinyml`, `edge-impulse`, `fall-detection`, `platformio`)
- [x] Enable GitHub Issues and set up labels that map to this checklist's structure — **deviation:** used `phase-1-setup` through `phase-8-docs` (8 phases, not 7 — matches the actual phase count in this file) plus the repo's default `bug`/`help wanted` labels
- [x] Create a GitHub Project (the built-in Projects board) with columns `Backlog / In Progress / Done` — [Fall Detection Build Roadmap](https://github.com/users/msohdy/projects/3). **Deviation:** one issue per phase (not one per task) was added to the board, each issue linking back to its section of this file for the detailed checklist — keeps the board readable while this file stays the source of truth for task-level detail.
- [x] Set milestones matching the phases, each with its issue attached — 8 milestones created matching the 8 phases in this file
- [ ] Add a `CODEOWNERS` or at least a note in `README.md` on who reviews PRs — **explicitly deferred** to closer to Phase 7/8, per plan
- [ ] Turn on GitHub Discussions — **explicitly deferred** until the project has outside visitors

## Phase 3 — Wiring

**Free/open-source tools to design and document the diagram**

- [x] [Fritzing](https://fritzing.org/) — **chosen primary tool** (switched from an initial Wokwi choice): open source, breadboard-style diagram, parts easy to find in Fritzing's library
- [x] [Wokwi](https://wokwi.com/) — considered first, not used
- [x] [KiCad](https://www.kicad.org/) — not needed for this project (no PCB planned for v1)
- [x] Pick one primary tool for the repo — **Fritzing** (deviation from the earlier Wokwi decision, made once actually building the diagram)

**Pin table** — **deviation:** the Neopixel is the board's onboard single WS2812 RGB LED (GPIO48), not an external strip, so there's no separate strip wiring or level-shifting concern.

| Signal | MPU6050 | Neopixel (onboard) | Buzzer (active) |
| --- | --- | --- | --- |
| Power | VCC → 3.3V | onboard, no wiring | + → **GPIO6** (switched power, not a fixed rail) |
| Ground | GND → GND | onboard | - → GND |
| Data/Signal | SDA → GPIO8 | GPIO48 (onboard) | *(none — see note below)* |
| Clock | SCL → GPIO9 | — | — |

- [x] Confirm your board's default I2C pins — **GPIO8 (SDA) / GPIO9 (SCL)**, the Arduino-ESP32 core's default `Wire.begin()` pins on ESP32-S3 (no strapping-pin conflicts), set explicitly rather than relying on board defaults since the board ID in `platformio.ini` doesn't exactly match the physical hardware
- [x] Confirm the buzzer type (passive vs active) — **confirmed active** via direct test: connecting VCC to 3.3V and GND with the third pin left unwired produced a steady, continuous tone, meaning it has its own internal driver circuit. This corrects an earlier passive guess based on an old, apparently-unrelated sample sketch that used `tone()`.
  - **Deviation — no dedicated signal pin:** this buzzer's 3rd pin turned out to be unused (confirmed: it buzzed with just VCC+GND wired, 3rd pin floating). There's no logic-level control input at all — the module just turns on whenever it has power. So control works by switching **power itself**: the wire originally planned for a fixed 3.3V rail instead goes to **GPIO6**, which sources power to the buzzer directly; GND stays on GND; the 3rd/mid pin is left disconnected. Driver code in Phase 5 uses `digitalWrite(GPIO6, HIGH/LOW)` to turn it on/off — confirmed working.
  - **Note for Phase 5:** driving the buzzer directly off a GPIO (rather than through a transistor) works for bring-up but isn't the most robust long-term design if the buzzer's current draw is on the high side for a GPIO pin (ESP32-S3 GPIOs recommend staying under ~20mA). Revisit with a transistor driver if it proves unreliable.
  - **PRD implication to revisit in Phase 5:** the PRD's per-state buzzer table calls for a distinct *tone* per concerning state (warning tone / siren / recovery chirp). An active buzzer can't vary pitch — only on/off timing patterns. Will need to use distinct *beep patterns* (e.g. different on/off rhythms) instead of distinct pitches to keep the "tell severity apart by sound alone" requirement.
- [x] Note the Neopixel strip's logic voltage — **N/A**, onboard single LED (GPIO48), not an external strip

**Physical build**

- [x] Breadboard the MPU6050, Neopixel, and buzzer per the diagram — done one component at a time, each verified with a real firmware test rather than just continuity: MPU6050 confirmed via I2C scanner (responds at `0x68`), buzzer confirmed via `digitalWrite` on/off toggling on GPIO6, Neopixel confirmed via a red/green/blue color-cycle test on GPIO48
- [x] Photograph the breadboard from a few angles for the docs — one photo taken and added to `docs/wiring/wiringImage.jpg`
- [x] If building the wearable form factor, plan strain relief on the wires before final assembly — **decision: staying on breadboard for v1**, powered by a USB powerbank (handheld, not worn or room-mounted). No enclosure/form-factor commitment yet, so strain relief is out of scope for now; revisit if/when a final form factor is chosen.
- [x] Add the finished wiring diagram + photos + pin table to `/docs` — `docs/wiring/fall-detection-wiring.fzz` (Fritzing source), `docs/wiring/fall-detection-wiring.png` (exported diagram), `docs/wiring/wiringImage.jpg` (photo), pin table in this file and in `README.md`

## Phase 4 — TinyML Data Collection & Training

**Setup**

- [x] Create a free [Edge Impulse](https://edgeimpulse.com/) account and a new project
- [x] Flash a minimal sketch to the ESP32-S3 that reads MPU6050 accel + gyro and prints to serial in the format Edge Impulse's Data Forwarder expects — streams `accX,accY,accZ,gyrX,gyrY,gyrZ` at ~50Hz via raw I2C register reads (no Adafruit_MPU6050 library — an earlier attempt using that library appeared to hang/produce no serial output, and raw register access matching a previously-known-working sketch was used instead). Confirmed producing real, varying sensor values. Sample rate tuned from an initial ~100Hz down to ~50Hz (still dense enough to characterize a fall's acceleration spike within the PRD's ~1-2s window).
  - **Debugging note:** hit a confusing failure where I2C reads returned a fixed garbage value (`Wire.read()` returning -1 for every byte, i.e. `Wire.requestFrom()` failing) despite the MPU6050 previously scanning fine at `0x68`. Root cause turned out to be the **ESP32-S3 board itself not being fully seated in the breadboard** — some pins (including GPIO8/9) had no reliable contact. A lit power LED on the MPU6050 was a red herring: it stayed faintly lit even with VCC disconnected, due to current backfeeding through the I2C pull-up resistors on the breakout — lesson for later debugging: a lit sensor LED doesn't guarantee a solid power connection.
- [x] Connect the Data Forwarder and confirm live samples appear in the Edge Impulse Data Acquisition tab — **deviation (two levels deep):**
  1. `npm install -g edge-impulse-cli` failed (`@serialport/bindings` needs native compilation via `node-gyp`, which requires Visual Studio Build Tools that aren't installed — a large, slow install to add just for this).
  2. Edge Impulse Studio's browser-based WebSerial "Connect a new device" flow was tried as a CLI-free alternative, but turned out to require the device firmware to speak Edge Impulse's AT-command remote-management protocol (`Timeout when waiting for >` error) — a completely different thing from the plain-CSV Data Forwarder protocol our sketch speaks. Not usable without writing that protocol into the firmware.
  - **Final approach:** built a custom local tool, [`tools/serial-data-logger.html`](../tools/serial-data-logger.html) — a self-contained Web Serial page (no CLI, no special firmware protocol) that connects to the board, logs incoming CSV lines to an editable table, and exports a clean CSV per recording session. Those CSVs are then imported into Edge Impulse via Studio's **Data acquisition → Upload data** CSV wizard instead of a live Data Forwarder connection.

**Per-class collection** (5 classes: standing, sitting, walking, dizzy, fall)

- [x] Standing / sitting / walking — collected via `tools/serial-data-logger.html` (1399 / 1900 / 1971 samples respectively)
- [x] Dizzy/unsteady — simulated with deliberately irregular gait; 1886 samples
- [x] Fall — **deviation:** since the device is handheld (breadboard + powerbank, not worn — see Phase 3), falls are simulated by holding the assembly and mimicking the arm/body motion of falling (quick drop + sudden stop) rather than an actual worn fall onto a mattress; 960 samples (smallest class, as expected). **Known limitation carried into Phase 8 docs:** this fall signature is a proxy, not a real worn-device fall, and the model's confusion matrix shows real evidence of this (see below) — a handheld mimicked fall and a staggering "dizzy" motion end up looking more similar in the IMU signal than a real worn fall would.
- [x] After each recording session, reviewed samples for mislabeled segments using the chart + drag-select delete in `tools/serial-data-logger.html`. That tool later also gained a **Load CSV** button so already-saved recordings in `data/raw/` can be reopened for a second cleanup pass.

Total: 8116 raw samples across the 5 classes.

**Split & balance**

- [x] Checked class balance — fall (960) is the smallest class as expected, others range 1399–1971. No explicit rebalancing done; noted as something to revisit if fall-detection accuracy needs further improvement.
- [x] Train/validation split — 80/20, held out automatically by the training tool (see below) via a shuffled split of the windowed samples.

**Impulse design & training — deviation: Edge Impulse abandoned entirely**

Edge Impulse was dropped as the training platform (not just the data-forwarder connection method noted above). Reasons and what replaced it:

- [x] **Why:** wanted a fully local, reproducible, no-external-account training pipeline consistent with this project's "no external dependency" pattern (same reasoning as building `serial-data-logger.html` instead of relying on Edge Impulse's device-connection flow). Also, a simple 5-class dense-network classifier doesn't need Edge Impulse's Spectral Analysis / DSP blocks — raw windowed IMU samples fed directly into a small dense net work well here.
- [x] **Built [`tools/tinyml-trainer.html`](../tools/tinyml-trainer.html)** — a self-contained TensorFlow.js page: upload a CSV per class, configure window size / epochs / learning rate / model name, train a `dense(16, relu) → dense(8, relu) → dense(numClasses, softmax)` network entirely in-browser, then export a plain C header with the raw float weight/bias arrays (no TFLite Micro runtime needed — Phase 5 firmware will do a hand-rolled forward pass instead).
- [x] **Bug found and fixed during training:** the first training runs showed `val_acc` stuck around 0.3–0.5 and bouncing around while `acc` climbed normally to ~0.84 — classic overfitting-looking symptom, but the real cause was that the windowed dataset was built class-by-class in sequence (all "fall" windows, then all "sit", etc.), and TensorFlow.js's `validationSplit` carves its slice off the *end* of the array *before* any epoch shuffling. The validation set was therefore almost entirely just the last class or two, not a representative mix. Fixed by shuffling the windowed `(X, y)` pairs together before training. After the fix, `val_acc` tracked `acc` smoothly as expected.
- [x] **Added a confusion matrix to the trainer** (computed on the same validation slice tf.js uses internally) after realizing overall accuracy alone doesn't reveal whether "fall" specifically is being missed — which is exactly the PRD's stated priority. It also auto-flags in red if any "fall" validation samples were misclassified.
- [x] **Window size tuning — this mattered a lot.** Started at window=5 samples (100ms at 50Hz), which is far shorter than the PRD's suggested ~1–2s and produced heavy fall↔dizzy confusion (a 100ms slice can't capture a fall's actual shape). Iterated up:

  | Window size | Duration @ 50Hz | Overall val_acc | Fall samples missed |
  | --- | --- | --- | --- |
  | 5 | 0.1s | ~0.87 (comparable to the very first Edge-Impulse-style attempt) | 68/209 (32.5%) |
  | 50 | 1.0s | 0.958 | 39/191 (20.4%) |
  | 75 | 1.5s | 0.963 | 23/205 (11.2%) — **accepted for now** |

  Fall↔dizzy remained the dominant confusion at every window size, consistent with the handheld-fall-simulation limitation noted above rather than being purely a hyperparameter problem.
- [ ] **Not fully met:** the PRD's "zero missed falls" bar is not actually hit — 11.2% of fall validation samples are still misclassified. Explicitly accepted as a known v1 limitation (to document plainly in Phase 8) rather than continuing to iterate indefinitely, given the handheld form factor is the more likely root cause at this point. Revisit if a wearable form factor or more/cleaner fall data becomes available.

**Export**

- [x] Final model: `include/fall_detection_model_data.h` — window=75 (450 input features = 75 samples × 6 channels), `dense(16)→dense(8)→dense(5)`, labels `fall, sit, stand, walk, dizzy`. No `/lib` dependency needed (no TFLite Micro) — Phase 5 firmware includes this header directly and implements the forward pass by hand.
- [x] Model version noted here: trained via `tools/tinyml-trainer.html`, window=75, 50 epochs, learning rate 0.001, final train acc 0.999 / val_acc 0.963 (see table above for the tuning history).

## Phase 5 — Firmware Coding & Pin Configuration

**Pin config**

- [x] Create `include/pins.h` with named constants for every pin used (I2C SDA/SCL = GPIO8/9, Neopixel = GPIO48 onboard, buzzer = GPIO6 switched power) — matches the pin table from Phase 3, so wiring changes only ever touch one file
- [x] Add library dependencies to `platformio.ini`: `Adafruit NeoPixel` (already added in Phase 3) and WiFi/HTTPS client (bundled with the ESP32 Arduino core). **Deviation from original plan:** no Edge Impulse export library and no MPU6050 driver library needed — see Drivers below.

**Drivers**

- [x] MPU6050 read loop — **deviation:** use the same raw I2C register access as `tools/mpu6050-data-forwarder.cpp` (registers 0x3B–0x48 via `Wire`), not the `Adafruit_MPU6050` library — an earlier attempt with that library hung with no serial output during Phase 4 bring-up, and the raw-register approach is already proven working at ~50Hz. Implemented in `include/mpu6050.h` + `src/mpu6050.cpp`, sampling at 50Hz into a 75-sample window (1.5s), matching exactly what `tools/tinyml-trainer.html` was trained on.
- [x] Model inference — **deviation:** no TFLite Micro. Implemented in `include/model_inference.h` + `src/model_inference.cpp` as a hand-rolled forward pass (`dense(450→16, ReLU) → dense(16→8, ReLU) → dense(8→5) → argmax`) over the raw float arrays in `include/fall_detection_model_data.h`.
  - **Gotcha hit and fixed:** `fall_detection_model_data.h` defines `LABELS[]` (and the weight/bias arrays) without `extern`, so including it directly from more than one `.cpp` file causes a linker "multiple definition" error — and would otherwise silently duplicate the model's ~160KB flash footprint per file that includes it. Fixed by making `model_inference.cpp` the *only* file that includes the generated header directly; everything else goes through `model_inference.h`, which mirrors the model's window-size/channel-count macros with a `static_assert` guard so a future retrain with different dimensions fails the build loudly instead of silently misbehaving.
  - **Confirmed working end-to-end** via a bring-up test: live MPU6050 samples → windowing → inference → predicted label printed over serial, producing sane results (mostly "sit" for a stationary device, as expected — no state-machine smoothing yet, so occasional single-frame noise is expected and will be handled by `CONFIRM_THRESHOLD` below).
- [x] Neopixel driver — `include/neopixel_driver.h` + `src/neopixel_driver.cpp`, a `VisualState` enum (`Standing/Sitting/Walking/Dizzy/Alarmed/Recovering`) with `neopixelSetState()` (called once on state change) and `neopixelTick()` (called every loop, non-blocking, drives the Alarmed pulse and Recovering amber→green fade off `millis()`). Confirmed all 6 states visually via a bring-up test.
- [x] Buzzer driver — **deviation:** buzzer is active with no signal pin (Phase 3) — driver is `digitalWrite(BUZZER_PIN, HIGH/LOW)` to switch its power directly, not `tone()`/`noTone()`. Implemented in `include/buzzer_driver.h` + `src/buzzer_driver.cpp` as a `BuzzerState` enum with distinct non-blocking on/off **beep patterns** per state (`Warning` = slow intermittent, `Siren` = fast continuous-feeling, `Recovery` = triple chirp + pause) instead of distinct tones. Confirmed audibly via the same bring-up test.

**State machine**

- [x] Implement the four states (NORMAL, DIZZY, ALARMED, RECOVERING) and transitions from the PRD's pseudocode/state diagram — `include/state_machine.h` + `src/state_machine.cpp`. Uses string comparison against `modelLabel()` rather than hardcoded class indices, so it stays correct even if the model is retrained with a different label order.
  - **Issue found during live testing, fixed in Phase 6:** ALARMED→RECOVERING originally required stand/dizzy/walk, excluding "sit". Live debug logging showed the model predicting "sit" for most of a real post-fall standing/walking attempt, which — combined with the sit exclusion — kept resetting the confirm counter and left the alarm stuck (siren never stopped). Not a state-machine logic bug; the debug log confirmed the code did exactly what it was told. Fixed in Phase 6 by broadening the exit criteria to include "sit" (any non-fall reading now counts) — safe to do since alerting had by then been decoupled from recovery detection entirely (see Phase 6 notes), so the worst case is stopping the siren a bit early, not missing an alert.
- [x] Implement `CONFIRM_THRESHOLD` and `RECOVER_CONFIRM_THRESHOLD` as sustained-reading counters, not single-frame triggers — `CONFIRM_THRESHOLD = 3` (~4.5s), `RECOVER_CONFIRM_THRESHOLD = 5` (~7.5s), counted in classifications at the ~0.67/sec (once per ~1.5s window) rate established below. (Initially set to 50/100 assuming a 50Hz classification rate; recalibrated after switching to non-overlapping-window classification — see the false-alarm fix below. Left as tunable constants for Phase 7 testing to adjust.)
- [x] **Deviation from the PRD's literal ALARMED exit condition:** by explicit choice, exiting ALARMED (siren stops, enters RECOVERING) now requires **stand, dizzy, or walk** — not the PRD's original "stand or sit." Any sign of movement/consciousness other than sitting still counts as recovering; a continued "fall" *or* "sit" reading keeps the siren going. RECOVERING → NORMAL (the final "all clear," which also sends the resolved Telegram message) still uses the original stand/sit criterion, unchanged.
- [x] Implement the ALARMED→RECOVERING→ALARMED relapse path (fall reading during RECOVERING jumps straight back to ALARMED and resets `alertSent` so a fresh Telegram message goes out)
- [x] **Real bug found during bring-up testing:** entering ALARMED on a single "fall" classification (as the PRD's pseudocode literally specifies) combined with classifying on a *sliding* window every new sample (~50Hz) caused spurious false alarms roughly every few seconds even at rest. The confusion matrix showed a small but nonzero false-fall rate (sit→fall, walk→fall, and especially dizzy→fall: ~1.2% of non-fall classifications overall) — at 50 classifications/second, that compounds to a ~46% chance of at least one false trigger per second. **Fixed without touching the single-frame-trigger logic**: switched from a sliding window (classify every sample) back to a fresh, non-overlapping window per classification (~0.67 classifications/sec) — this is also what the model was actually validated on (independent windows, not overlapping ones), and cuts the false-alarm rate to roughly once every couple of minutes. Neopixel/buzzer `tick()` calls still run every ~20ms during window collection so animations stay smooth despite the lower classification rate. Confirmed via a 35-second stationary test: zero false alarms.

**Telegram integration**

- [x] Store the bot token, chat ID, and WiFi credentials in a `secrets.h` that's git-ignored (never commit these) — `include/secrets.h` (git-ignored) + `include/secrets.h.example` (committed template). Chat ID was retrieved by messaging the bot once, then fetching `https://api.telegram.org/bot<TOKEN>/getUpdates` and reading the `chat.id` field — the `.env` file from Phase 1 had saved the lookup *URL* instead of the actual numeric ID, so this had to be done properly here.
- [x] Implement `sendTelegramMessage()` as an HTTPS GET to the Bot API's `sendMessage` endpoint (`include/telegram.h` + `src/telegram.cpp`, using `WiFiClientSecure` + `HTTPClient`), called once on ALARMED entry (`alertSent` flag) and once on RECOVERING→NORMAL resolution. Returns `bool` (success/failure) rather than being fire-and-forget for the fall alert specifically — `alertSent` is only set `true` if the send actually succeeded, so it naturally retries on the next classification if WiFi wasn't ready yet, matching the PRD's pseudocode more precisely than an earlier draft that marked it sent unconditionally.
  - **Security note:** uses `WiFiClientSecure::setInsecure()` (no certificate pinning) — a common simplification for a hobbyist project, at the cost of no protection against a MITM on the local network. Documented in README's Build Log rather than silently done.
- [x] Make the WiFi/Telegram call non-blocking or at least short-timeout — `sendTelegramMessage()` checks `WiFi.status()` and returns immediately (no blocking wait) if not already connected; `telegramInit()`'s `WiFi.begin()` call itself is non-blocking (connects in the background). The actual HTTPS GET (only reached when already connected) has a 4-second timeout.
- [x] Wire it all together in `main.cpp`'s loop per the PRD pseudocode — confirmed working end-to-end: triggering a simulated fall produced a real Telegram message on-device.

## Phase 6 — Build, Flash & Upload

- [x] `pio run` to compile — **found and fixed a real build-blocking bug**: `include/secrets.h` had a missing closing quote on `TELEGRAM_CHAT_ID` (`"529206226` with no trailing `"`), a silent typo that broke every build. Unrelated to firmware logic. Also note: the PlatformIO CLI isn't on `$PATH` in this setup — invoked directly from `~/.platformio/penv/bin/pio` (same binary the VS Code extension uses under the hood).
- [x] Connect the ESP32-S3 over USB, confirm the correct serial port is detected (`pio device list`) — confirmed at `/dev/cu.usbmodem30EDA0A8ADE01`, "Espressif ESP32-S3-USB-OTG"
- [x] `pio run --target upload` to flash — **deviation: this board does NOT auto-reset into the bootloader.** esptool's normal DTR/RTS reset trick fails with "No serial data received" every time. Required manually holding **BOOT**, then pressing/releasing **RESET** (or unplug/replug USB) *while still holding BOOT*, before every single upload. While in bootloader mode the board re-enumerates under a **different port** (e.g. `/dev/cu.usbmodem101` or `.../2101`) as "USB JTAG/serial debug unit" — upload to that port, not the app one. After a successful upload it hard-resets back to the original port/name on its own.
- [x] Open the serial monitor (`pio device monitor`) and confirm sensor readings, inference output, and WiFi connection logs look sane before disconnecting from USB — **deviation: no such logging existed at all going into Phase 6.** Added a per-cycle `[cycle] predicted=<label> wifi=<connected|disconnected>` heartbeat in `main.cpp`, plus `[state]` transition logs and `[telegram]`/`[wifi]` send/connect logs in `state_machine.cpp`/`telegram.cpp`. This is what made the bugs below diagnosable at all rather than guessed at from behavior. `pio device monitor` itself can't run non-interactively from a script — needs a real terminal (or a pty wrapper like `script`) if scripting serial capture.
- [ ] Do a first untethered test: battery power (if wearable) or wall power (if room device), confirm Neopixel/buzzer behavior matches expectations for a basic "standing still" baseline — **partially done, and explicitly left open by decision**: extensive power-bank testing happened during this phase (see the bugs below, most of which were found *because of* untethered testing), but a clean confirmation run specifically with the final async-Telegram-task firmware hasn't been done off-USB yet. **Decision (2026-09-17):** the Phase 6 GitHub issue was closed anyway rather than blocking on this — the phase's core objective (build/flash/upload working, major bugs found and fixed) is solidly met, and this remaining item is being carried forward as a quick Phase 7 sanity check instead of a Phase 6 blocker.
- [x] Note the exact `platformio.ini` board/framework versions that worked in `/docs` — `platform = espressif32 @ 7.0.1`, `framework-arduinoespressif32 @ 3.20017.241212+sha.dcc1105b`, `tool-esptoolpy @ 4.11.0`, board `esp32s3usbotg`

**Bugs found and fixed during Phase 6 bring-up (not in the original plan — added here per the "record deviations" rule):**

- [x] **Real bug: a second fall's Telegram alert silently never sent.** Live testing showed: fall #1 → alert sent OK → recovered → resolved message sent OK → fall #2 → **no alert at all**, no error surfaced anywhere. Root cause (found via the new serial logging above): **WiFi silently dropped and never reconnected on its own** — `WiFi.status()` sat at disconnected for 25+ seconds straight with zero recovery attempts, despite `WiFi.setAutoReconnect(true)`. The state machine itself was doing exactly the right thing the whole time (fresh `alertSent = false` on every new alarm, retrying every cycle) — the transport underneath it had just died. **Fix:** `WiFi.setSleep(false)` in `telegramInit()` (disables ESP32 modem sleep, a known cause of exactly this silent-drop symptom) plus a new `telegramTick()` in `telegram.cpp`/`.h` that actively retries `WiFi.begin()` (throttled to once per 5s) whenever disconnected, called every ~20ms from `main.cpp`'s sampling loop so recovery isn't gated on the slower classification cadence.
- [x] **Real bug: repeated failed Telegram sends risked hanging the device.** After the WiFi fix, one test still showed a failed send attempt followed by the serial log going completely silent (heartbeat included) for well past what should have printed a retry — consistent with a second back-to-back TLS handshake (`WiFiClientSecure` + `HTTPClient`, freshly constructed each call) hanging rather than failing fast. **Fix:** throttled Telegram send retries to at most once per 5s (`ALERT_RETRY_INTERVAL_MS`) instead of every ~1.5s classification cycle, in `state_machine.cpp`.
- [x] **State machine redesigned around a "did they get up" question — product decision made mid-Phase-6, deviation from the original single-fall-triggers-alert design:** a fall now enters a new `FALLEN` state with a short (4s, `FALL_CONFIRM_DELAY_MS`) debounce before confirming — filters a single noisy frame, nothing more. **Explicit decision: the Telegram alert always fires once a fall is confirmed, never conditionally on whether the person seems to recover.** An earlier version of this redesign waited up to 20 seconds to decide whether to alert *at all*, canceling quietly with no message ever sent if the person got back up in time — this was built, tested, and explicitly rejected: missing a real fall is worse than an occasional extra alert, and gating the alert on the same recovery-detection logic that already had a known bug (see the Phase 5 ALARMED→RECOVERING note above) was too risky. Recovery is now fully decoupled from the alert: after `ALARMED`, sustained stand/dizzy/walk readings — no time limit, "whenever" — move to `RECOVERING` then `NORMAL` and send the "Resolved" message, unchanged from the original design. Buzzer escalation added to match: intermittent siren (`BuzzerState::Siren`) during the `FALLEN` debounce, escalating to a continuous tone (`BuzzerState::SirenConfirmed`) once confirmed.
- [x] **Confirmed end-to-end on real hardware, twice in a row, with real Telegram messages received on a phone:** fall → alert sent → recovered → resolved sent → second fall → alert sent again. This is the exact failure scenario reported at the start of Phase 6 testing, now fixed and verified.

**More bugs found and fixed during untethered (power-bank) field testing, after the above:**

- [x] **Real bug: a pending alert could be abandoned if the state moved on before WiFi came up.** The alert-send retry lived inside the `ALARMED` switch case, so if the person recovered (state left `ALARMED`) before WiFi ever connected, the send attempts simply stopped — the alert was silently lost, not just delayed. Found via a power-bank test where WiFi took 20-35s to reconnect after a cold boot, well longer than a quick recovery. **Fix:** message delivery (`alertSent`/`resolvedSent` retry) was hoisted out of the state switch to run unconditionally every cycle, independent of `AppState` — a pending message now keeps retrying forever until it actually succeeds, no matter what the state machine does afterward.
- [x] **Real bug: the fall-confirmation debounce could stretch to 15-20+ seconds instead of ~4s.** The debounce timer was restarted on every repeated "fall" classification (meant for a genuine relapse), but a single real fall's settling motion can itself span several consecutive classification windows, each one pushing the timer out further. **Fix:** the timer is now set once on the first fall reading and never reset within the same `FALLEN` episode — escalation is bounded to a fixed delay from the *first* reading, full stop.
- [x] **WiFi retry logic was fighting itself, stretching a normal ~5-10s connect out to 60-90+ seconds.** `telegramTick()` called `WiFi.begin()` again every 5s whenever disconnected — but calling `WiFi.begin()` while a connection attempt is already in progress can abort and restart that handshake, so a slow WPA2/DHCP negotiation kept getting interrupted before it could finish. **Fix:** throttle raised to 15s, giving a real attempt room to complete.
- [x] **Discovered (not a firmware bug): a home router can temporarily rate-limit/block a device that reassociates too aggressively.** After the above bug was live for a while, WiFi stopped connecting *at all* (not just slowly) on the original router, even after fixing the retry throttle — and it later connected fine again after enough time passed / other network changes. Most likely a router-side anti-flood defense triggered by the earlier 5s-retry storm. Not fixable from firmware; a router power-cycle or a wait typically clears it.
- [x] **Discovered (not a firmware bug): phone hotspots can default to 5GHz, which the ESP32-S3 (2.4GHz-only) cannot see at all.** Switching WiFi credentials to a phone hotspot for testing (to rule out the router block above) also failed to connect, for a different reason — worth checking a hotspot's band/"maximize compatibility" setting before assuming a firmware issue.
- [x] **Real build-tooling gotcha: editing `secrets.h` doesn't always trigger a relink.** After changing `WIFI_SSID`/`WIFI_PASSWORD` back to the router's credentials, `pio run` recompiled `telegram.cpp.o` (correctly, timestamp-wise) but did **not** relink `firmware.elf`/`firmware.bin` — verified by comparing file timestamps, and confirmed by `strings`-searching the built `.bin` for the expected SSID. A board flashed after an edit like this can silently still be running old credentials. **Workaround used:** `pio run --target clean` before rebuilding whenever a git-ignored header like `secrets.h` changes; verify with `strings firmware.bin | grep <expected-value>` if in doubt.
- [x] **Real bug (the actual root cause of "stuck" states and 10+ second alert latency): the Telegram send blocked the entire main loop.** `sendTelegramMessage()` is a real, synchronous HTTPS/TLS call, and it was being invoked directly from `stateMachineUpdate()`, which runs in the same single-threaded loop as IMU sampling, classification, and the buzzer/Neopixel ticks. While a send was in flight (which can take anywhere from under a second to several seconds, especially retrying on a flaky connection), *nothing else in the firmware could run* — no new samples, no new classifications, frozen animations — which looked exactly like the state machine being stuck, because the whole loop genuinely was. **Fix:** moved all Telegram sending onto a dedicated FreeRTOS task (`xTaskCreatePinnedToCore`, pinned to core 0, separate from Arduino's `loop()` on core 1) in `telegram.cpp`. `state_machine.cpp` now only calls fire-and-forget `telegramSendFallAlert()`/`telegramSendResolved()`; the background task owns all retry/backoff/delivery logic and the actual blocking network calls, so a slow or retrying send can never stall sensor sampling or classification again. Confirmed via serial log: `[cycle]` heartbeat lines kept appearing at a normal, steady cadence right through a live send and full recovery sequence.
- [x] **Recovery criteria broadened back to include "sit"** (`isRecoverySign()` now equals "any non-fall reading"), reverting the Phase 5 exclusion that caused the earlier stuck-alarm bug. Safe to do now that the alert no longer depends on recovery detection succeeding — worst case is stopping the siren a little early, not missing an alert.
- [x] **Added a purple-flash-x3 Neopixel indicator on WiFi connect** (`neopixelFlashWifiConnected()` in `neopixel_driver.h/.cpp`, triggered from `main.cpp`), non-blocking (ticked via `neopixelTick()` like everything else), so WiFi status is visible during untethered/battery testing without a serial monitor.
- [x] **Confirmed end-to-end again after all of the above, on the original home router, with the async Telegram task in place:** fall → alert sent OK → recovered cleanly (no longer stuck) → resolved message sent OK (after one transient retry) → classification heartbeat never skipped a beat throughout. Both messages confirmed received on a phone.

## Phase 7 — Testing & Validation

Validate against the PRD's own success criteria:

- [ ] **Carried over from Phase 6:** do a clean, final untethered (battery power) confirmation run with the current firmware (async Telegram task, fixed debounce, broadened recovery) — a basic "standing still" baseline plus one full fall→alert→recover cycle, off USB
- [ ] **Classifier accuracy** — re-check ≥90% on held-out data isn't just an Edge Impulse number; run live on-device with samples the model has never seen and log the confusion pattern, especially fall-vs-standing
- [ ] **End-to-end latency** — time from a simulated fall event to the Telegram message landing on a phone; target under \~5 seconds on stable WiFi. Log actual numbers across several trials, not a single run
- [ ] **Zero missed falls** — this is the PRD's explicit priority over false-positive rate. Run repeated fall simulations (forward/backward/sideways, different speeds) and treat any miss as a blocker, not a tuning footnote
- [x] Test the WiFi-down path deliberately: confirm the local alarm (Neopixel + siren) still fires with WiFi disabled, and that the main loop doesn't stall waiting on the Telegram call — extensively exercised during Phase 6 field testing (WiFi was down for extended periods in several tests); confirmed the siren/light always fired regardless, and after moving Telegram sending to a background task (Phase 6), confirmed via serial log that classification cycles never stall even while a send is actively in flight or retrying
- [x] Test the relapse path: trigger ALARMED → let it reach RECOVERING → trigger another fall before it reaches NORMAL, confirm it jumps back to ALARMED and sends a fresh alert — observed live during Phase 6 testing (`RECOVERING -> ALARMED (predicted=fall)` in the serial log), fresh alert sent successfully
- [ ] Test recovery false-clear resistance: brief "standing" misreads during ALARMED should reset the confirm counter, not silence the alarm — deliberately inject a few noisy frames and confirm this holds
- [ ] If wearable: test battery life under continuous sampling + occasional WiFi bursts, and log it (open-source users will ask)
- [ ] Log every test run (setup, result, date) somewhere in `/docs` — this becomes the validation section of the writeup, not something to reconstruct from memory later

## Phase 8 — Documentation & Open-Source Release

- [ ] Write the README from the notes you've collected phase by phase — don't write it from scratch at the end: problem statement, BOM with links, wiring diagram + photos, setup instructions (PlatformIO, Edge Impulse), and a demo GIF/video of a simulated fall triggering the alert
- [ ] Publish the wiring diagram (Fritzing/Wokwi export) and pin table in `/docs`
- [ ] Document the dataset: class list, collection method per class, final sample counts, and either the exported dataset or clear instructions for reproducing it (raw motion data is usually fine to share; note any privacy considerations if it includes identifiable video/audio, which this project doesn't)
- [ ] Include the trained model export (or a link/version note if it's too large for git) so people can flash and test without retraining from zero
- [ ] Document known limitations plainly — false positive rate, what "dizzy" simulation doesn't capture about real dizziness, battery life if wearable, WiFi dependency for the remote alert — this is what separates a genuinely reproducible open-source project from a demo
- [ ] Add a CONTRIBUTING.md if you want outside contributions, and confirm the LICENSE file from Phase 1 is in place
- [ ] Do a final clean-clone test: pull the repo fresh on another machine (or ask someone else to), follow only the README, and see how far they get without asking you anything — fix whatever trips them up
- [ ] Publish: push to GitHub, write a short launch post (blog/LinkedIn/forum) summarizing the problem, the approach, and linking the repo and demo video

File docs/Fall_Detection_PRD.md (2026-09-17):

# PRD: Fall Detection & Alert System

2026-09-17 · @u_Gd73xkkFmo9snIgr0fdFzg

An ESP32-S3 wearable/room device classifies body state (standing, sitting, walking, dizzy, fall) from MPU6050 data on-device, drives Neopixel/buzzer feedback per state, and sends a Telegram alert to an emergency contact when a fall is confirmed.

## Goals & Scope

**Problem.** A person living or working alone has no automatic way to signal a fall. Manual alerting (pressing a button, calling out) fails exactly when someone is unconscious or too disoriented to act.

**Goals**

- Classify body state in real time from wrist/waist-mounted IMU data: standing, sitting, walking, dizzy, fall.
- Give silent, glanceable feedback (Neopixel color) for every state, so the device is not alarming during normal activity.
- Escalate audibly only for concerning states (dizzy, fall), with a distinct tone per state so a caregiver can tell severity from sound alone.
- On a confirmed fall, notify a remote emergency contact over Telegram without requiring the fallen person to act.
- Require a sustained, confirmed return to normal activity before silencing an alarm, to avoid false-clears from momentary misreads.

**Non-goals (v1)**

- No health diagnosis or vital-sign monitoring — the device infers activity state from motion only.
- No GPS/location in the alert (device is assumed stationary within one home/room; add location as a v2 item if the wearable becomes mobile).
- No two-way voice or video in the alert — the Telegram message is informational, not a call.

**Success criteria**

- 5-class classifier reaches acceptable accuracy on held-out data (target ≥90%, tune per Edge Impulse validation).
- End-to-end latency from fall event to Telegram message received under \~5 seconds on a stable WiFi connection.
- Zero missed real falls during test scenarios take priority over false-positive rate — tune the confirm thresholds accordingly.

## Devices & Bill of Materials

| Component | Role in this project |
| --- | --- |
| ESP32-S3 | Runs the TFLite Micro classifier, state machine, and WiFi/Telegram calls |
| MPU6050 (gyroscope + accelerometer) | Primary sensor — feeds the windowed IMU data the classifier reads |
| Neopixel LEDs (onboard) | Silent per-state color feedback |
| Buzzer | Distinct tone per concerning state (dizzy, fall, recovering) |
| WiFi (onboard ESP32-S3 radio) | Sends the Telegram alert on confirmed fall |

**Not used in this project:** camera, DHT11, IR sensor, ultrasonic sensor, fan/relay, servo motor — reserved for the Focus Mode Tracking PRD.

## System Architecture

This project is almost entirely on-device: the only "bridge" beyond the ESP32-S3 is the outbound call to Telegram's cloud API, so there is no local dashboard or laptop process in the loop.

```mermaid
flowchart LR
    IMU[MPU6050<br/>accel + gyro] --> WIN[Sample window<br/>~1-2s]
    WIN --> TFL[TFLite Micro<br/>5-class classifier]
    TFL --> SM[State machine<br/>NORMAL/DIZZY/ALARMED/RECOVERING]
    SM --> LED[Neopixel driver]
    SM --> BUZ[Buzzer tone player]
    SM -->|on ALARMED entry| WIFI[ESP32-S3 WiFi]
    WIFI -->|HTTPS POST| BOT[Telegram Bot API]
    BOT --> PHONE[Emergency contact's<br/>Telegram app]
```

*Reading it: sensor → on-device inference → state machine → local actuators (always) and a one-shot cloud call (only on the ALARMED transition). Everything left of the WiFi node runs entirely on the ESP32-S3 with no network dependency, so the local alarm still works if WiFi is down — only the remote notification is lost.*

## State Machine

```mermaid
stateDiagram-v2
    [*] --> NORMAL
    NORMAL --> DIZZY: prediction = dizzy
    NORMAL --> ALARMED: prediction = fall
    DIZZY --> NORMAL: prediction = standing/sitting/walking
    DIZZY --> ALARMED: prediction = fall
    ALARMED --> RECOVERING: standing/sitting held for\nCONFIRM_THRESHOLD
    RECOVERING --> NORMAL: standing/sitting held for\nRECOVER_CONFIRM_THRESHOLD
    RECOVERING --> ALARMED: prediction = fall (relapse)
```

| State | Neopixel | Buzzer |
| --- | --- | --- |
| Standing / Sitting / Walking (within NORMAL) | Blue / Cyan / Green | Silent |
| Dizzy | Amber | Intermittent warning tone |
| Alarmed (fall) | Red, pulsing | Continuous paramedic siren |
| Recovering | Amber → Green fade | Short descending recovery chirp |

Recovery out of ALARMED and out of RECOVERING each require a **sustained** run of normal readings (`CONFIRM_THRESHOLD`, `RECOVER_CONFIRM_THRESHOLD`), not a single frame — a single "standing" misread should never silence a real emergency early. A relapse (fall reading during RECOVERING) jumps straight back to ALARMED rather than starting a fresh detection cycle.

## Pseudocode

```
state = NORMAL   // NORMAL, DIZZY, ALARMED, RECOVERING
confirm_counter = 0
alert_sent = false

loop every N ms:
    window = collect_imu_samples(window_size)
    prediction = tinyml_classify(window)  // standing, sitting, walking, dizzy, fall
    update_neopixel(prediction, state)

    if state == NORMAL:
        if prediction == FALL:
            state = ALARMED
            start_siren()
            alert_sent = false
        elif prediction == DIZZY:
            state = DIZZY
            start_warning_tone()

    elif state == DIZZY:
        warning_tone_tick()
        if prediction == FALL:
            stop_warning_tone()
            state = ALARMED
            start_siren()
            alert_sent = false
        elif prediction in [STANDING, SITTING, WALKING]:
            stop_warning_tone()
            state = NORMAL

    elif state == ALARMED:
        siren_tick()
        if not alert_sent and wifi_connected():
            send_telegram_message(EMERGENCY_CHAT_ID,
                "Fall detected at " + get_timestamp() + ". Siren active.")
            alert_sent = true   // fire once per event, never resend while ALARMED

        if prediction in [STANDING, SITTING]:
            confirm_counter += 1
            if confirm_counter >= CONFIRM_THRESHOLD:
                stop_siren()
                start_recovery_tone()
                state = RECOVERING
                confirm_counter = 0
        else:
            confirm_counter = 0   // any wobble resets — must be a clean, sustained recovery

    elif state == RECOVERING:
        recovery_tone_tick()
        if prediction in [STANDING, SITTING]:
            confirm_counter += 1
            if confirm_counter >= RECOVER_CONFIRM_THRESHOLD:
                stop_recovery_tone()
                state = NORMAL
                if wifi_connected():
                    send_telegram_message(EMERGENCY_CHAT_ID, "Resolved: back to normal activity.")
        elif prediction == FALL:
            stop_recovery_tone()
            start_siren()
            state = ALARMED
            confirm_counter = 0
            alert_sent = false   // relapse — send a fresh alert
        else:
            confirm_counter = 0
```

Implementation notes:

- `siren_tick()`, `warning_tone_tick()`, `recovery_tone_tick()` must be non-blocking (driven by `millis()`, not `delay()`), or the IMU sampling loop stalls while a tone plays.
- The Telegram call should never block the main loop — treat WiFi failure as "local alarm still fires, remote notification is skipped this cycle."

## Data & Training Plan

**Tooling:** Edge Impulse, using its Data Forwarder to stream MPU6050 samples over serial straight into data acquisition — avoids hand-logging CSVs.

**Pipeline:** Spectral Analysis + Classification impulse (Edge Impulse's standard template for accelerometer/gyro continuous motion recognition), deployed as a C++/Arduino library into the ESP32 sketch.

**Per-class collection notes:**

- Standing, sitting, walking — straightforward to capture directly, several minutes each, varied pace/posture.
- Dizzy/unsteady — hardest class; simulate by walking with deliberately irregular gait (staggering, uneven steps) since real dizziness isn't reproducible on demand. Label carefully and expect this class to need the most iteration.
- Fall — simulate onto a soft surface (mattress/mat) from multiple angles (forward, backward, sideways) to cover different acceleration/orientation signatures.

**Split:** standard train/validation/test split per class, with class balance checked before training since fall/dizzy samples will naturally be fewer than standing/walking.

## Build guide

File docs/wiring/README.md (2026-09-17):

# Wiring diagram

- `fall-detection-wiring.fzz` — Fritzing project file (source, editable)
- `fall-detection-wiring.png` — exported breadboard-view image, embedded in the main [README.md](../../README.md#wiring)

See the pin table in [docs/TASKS.md](../TASKS.md#phase-3--wiring) and [README.md](../../README.md#wiring) for the exact GPIO assignments this diagram should match.

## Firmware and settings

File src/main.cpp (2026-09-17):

#include <Arduino.h>
#include "mpu6050.h"
#include "model_inference.h"
#include "neopixel_driver.h"
#include "buzzer_driver.h"
#include "state_machine.h"
#include "telegram.h"
#include <WiFi.h>

// Main firmware loop. Keeps the loop itself thin per the PRD: sample,
// classify, tick the state machine and drivers.
//
// Classifies on a fresh, non-overlapping window each cycle (not a
// sliding window updated every sample) -- this matches how the model
// was actually validated (independent windows, not overlapping ones)
// and keeps the classification rate low enough that the model's
// measured ~1.2% false-fall-classification rate doesn't compound into
// frequent false alarms. An earlier sliding-window version classified
// on every new sample (50Hz), and the resulting ~50x higher
// classification rate caused spurious ALARMED triggers roughly every
// few seconds even at rest -- see docs/TASKS.md (Phase 5) for the math.

float window[MODEL_INPUT_FEATURES];

void setup() {
  Serial.begin(115200);
  delay(1000);

  mpu6050Init();
  neopixelInit();
  buzzerInit();
  stateMachineInit();
  telegramInit();

  Serial.println("Fall Detection System starting.");
}

void loop() {
  // Tick the animations every ~20ms during window collection (not just
  // once per full window) so the Alarmed pulse / buzzer patterns stay
  // smooth, even though classification itself only happens once per
  // window below.
  for (int i = 0; i < MODEL_WINDOW_SIZE; i++) {
    mpu6050ReadSample(&window[i * MODEL_SENSOR_CHANNELS]);
    neopixelTick();
    buzzerTick();
    telegramTick();
    delay(20);  // ~50Hz, matches training data rate
  }

  int predicted = modelPredict(window);
  Serial.printf("[cycle] predicted=%s wifi=%s\n", modelLabel(predicted),
                WiFi.status() == WL_CONNECTED ? "connected" : "disconnected");
  stateMachineUpdate(predicted);

  // One-shot WiFi connect/drop logging -- lets the serial monitor show
  // exactly when the link comes up or disappears, instead of only
  // inferring it indirectly from Telegram send failures.
  static bool wasConnected = false;
  bool isConnected = WiFi.status() == WL_CONNECTED;
  if (isConnected && !wasConnected) {
    Serial.printf("[wifi] connected, IP=%s\n", WiFi.localIP().toString().c_str());
    neopixelFlashWifiConnected();  // purple x3 -- visible without a serial monitor
  } else if (!isConnected && wasConnected) {
    Serial.println("[wifi] connection lost");
  }
  wasConnected = isConnected;
}

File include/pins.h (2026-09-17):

#ifndef PINS_H
#define PINS_H

// Pin assignments -- see docs/TASKS.md (Phase 3) and README.md's Wiring
// section for how these were determined. Change wiring? Change it here,
// nowhere else.

#define PIN_I2C_SDA 8
#define PIN_I2C_SCL 9

// Onboard single WS2812 RGB LED (not an external strip).
#define PIN_NEOPIXEL 48
#define NEOPIXEL_COUNT 1

// Active buzzer with no signal pin -- GPIO6 switches its power directly
// (digitalWrite HIGH/LOW), not tone()/noTone(). See README's Build Log.
#define PIN_BUZZER 6

#endif  // PINS_H

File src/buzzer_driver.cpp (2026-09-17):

#include "buzzer_driver.h"
#include "pins.h"
#include <Arduino.h>

namespace {

struct BeepSegment {
  unsigned long durationMs;
  bool on;
};

const BeepSegment WARNING_PATTERN[] = {
  {100, true}, {900, false},
};
const BeepSegment SIREN_PATTERN[] = {
  {200, true}, {200, false},
};
const BeepSegment RECOVERY_PATTERN[] = {
  {80, true}, {80, false},
  {80, true}, {80, false},
  {80, true}, {1500, false},
};

BuzzerState currentState = BuzzerState::Silent;
unsigned long stateStartMs = 0;

void applyPattern(const BeepSegment* pattern, int count, unsigned long elapsed) {
  unsigned long total = 0;
  for (int i = 0; i < count; i++) total += pattern[i].durationMs;
  unsigned long phase = elapsed % total;
  unsigned long acc = 0;
  for (int i = 0; i < count; i++) {
    acc += pattern[i].durationMs;
    if (phase < acc) {
      digitalWrite(PIN_BUZZER, pattern[i].on ? HIGH : LOW);
      return;
    }
  }
}

}  // namespace

void buzzerInit() {
  pinMode(PIN_BUZZER, OUTPUT);
  buzzerSetState(BuzzerState::Silent);
}

void buzzerSetState(BuzzerState state) {
  currentState = state;
  stateStartMs = millis();
  if (state == BuzzerState::Silent) {
    digitalWrite(PIN_BUZZER, LOW);
  }
}

void buzzerTick() {
  unsigned long elapsed = millis() - stateStartMs;

  switch (currentState) {
    case BuzzerState::Silent:
      break;  // already off from buzzerSetState()
    case BuzzerState::Warning:
      applyPattern(WARNING_PATTERN, 2, elapsed);
      break;
    case BuzzerState::Siren:
      applyPattern(SIREN_PATTERN, 2, elapsed);
      break;
    case BuzzerState::SirenConfirmed:
      digitalWrite(PIN_BUZZER, HIGH);  // continuous tone, no pattern
      break;
    case BuzzerState::Recovery:
      applyPattern(RECOVERY_PATTERN, 6, elapsed);
      break;
  }
}

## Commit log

2026-09-17 Phase 1: PlatformIO project scaffold, license, repo structure
    Adds the PlatformIO project (board esp32s3usbotg, framework arduino),
    standard repo layout (src/include/lib/test/data), MIT license, and
    records Phase 1 decisions/deviations in docs/TASKS.md and README.md.
2026-09-17 Phase 2: GitHub repo, Issues, labels, milestones, Projects board
    Creates the public GitHub repo, phase-mapped Issue labels, milestones,
    and a Projects board (one issue per phase, linked back to docs/TASKS.md
    for task-level detail). Records deferred items (CODEOWNERS, Discussions)
    and other Phase 2 decisions in docs/TASKS.md and README.md.
2026-09-17 Phase 3: wiring pin table, Fritzing diagram, component bring-up tests
    Finalizes the pin table (MPU6050 on I2C GPIO8/9, active buzzer on
    GPIO6 via switched power, onboard Neopixel on GPIO48). Each component
    verified individually with a real firmware test rather than just
    continuity checks. Adds Fritzing diagram + breadboard photo to
    docs/wiring/, and records wiring-phase decisions/deviations in
    docs/TASKS.md and README.md.
    [fall-detection-wiring.fzz]
2026-09-17 Phase 4: Edge Impulse account + MPU6050 data-forwarder sketch
    Adds a raw-register MPU6050 streaming sketch (accel + gyro,
    comma-separated, ~100Hz) for Edge Impulse's Data Forwarder. Records
    the debugging trail for a confusing I2C failure that traced back to
    the ESP32-S3 board not being fully seated in the breadboard.
    [main.cpp]
2026-09-17 Phase 4: custom Web Serial data logger, 50Hz sample rate
    Adds tools/serial-data-logger.html, a self-contained Web Serial page
    for capturing MPU6050 CSV data, built after both edge-impulse-cli and
    Edge Impulse Studio's WebSerial device flow turned out to be dead ends
    for this setup. Tunes the sketch to ~50Hz and records the fall-class
    simulation approach for the current handheld form factor.
2026-09-17 Set up data/raw/ for git-ignored raw session recordings
    Raw per-class CSV recordings from the data logger stay local; only a
    few representative samples per class get committed to data/.
2026-09-17 Data logger: add time-series chart with drag-to-select cleanup
    Adds a per-field-normalized line chart (toggleable legend) with
    click-and-drag range selection feeding into the existing row-delete
    flow, for visually spotting and removing non-representative segments
    (e.g. rest periods between fall attempts). Defaults to 6 fields
    (ax,ay,az,gx,gy,gz) matching the current data-forwarder sketch.
2026-09-17 Data logger: add Clear All button with confirmation
    Adds a Clear All button next to Delete Selected (disabled until there
    is data, confirms before wiping since it's irreversible). Confirmed
    Delete Selected's enable-on-checkbox-select behavior was already
    correct.
2026-09-17 Data logger: UI polish + usage docs with screenshot and pipeline
    Fixes live monitor growing instead of scrolling (flex min-height
    circularity with grid stretch, resolved by measuring and applying the
    left column's height directly in JS), stabilizes the Connect/Disconnect
    button width, and adds a baud-rate tooltip/hint for non-embedded users.
    Adds tools/README.md with usage instructions and a data-collection
    pipeline diagram, plus a screenshot referenced from both it and the
    main README.
2026-09-17 Phase 4 complete: custom TensorFlow.js trainer, drop Edge Impulse for training
    Adds tools/tinyml-trainer.html, a self-contained in-browser trainer
    (dense NN, no TFLite Micro) with a confusion matrix specifically
    checking fall misses, replacing Edge Impulse for training entirely
    (not just the earlier data-connection workaround). Documents the
    window-size tuning journey (5 -> 50 -> 75 samples) and a real
    validationSplit shuffling bug found and fixed along the way.
    Adds a Load CSV feature to serial-data-logger.html for re-reviewing
    saved recordings. Final model (window=75, val_acc 0.963) committed as
    include/fall_detection_model_data.h; 11.2% fall miss rate accepted as
    a known v1 limitation ti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
2026-09-17 Phase 5: pin config, MPU6050 driver, hand-rolled model inference
    Adds include/pins.h, a raw-register MPU6050 driver matching the Phase
    4 data-forwarder exactly, and a hand-rolled dense-network forward pass
    over fall_detection_model_data.h (no TFLite Micro). Fixes a multiple-
    definition linker error caused by the generated model header lacking
    extern declarations, by confining its inclusion to model_inference.cpp
    and mirroring its dimension macros elsewhere with a static_assert
    guard. Confirmed working end-to-end via a live bring-up test.
    [main.cpp, mpu6050.cpp, pins.h]
2026-09-17 Phase 5: Neopixel and buzzer drivers, confirmed via bring-up test
    Neopixel driver uses a VisualState enum with a setState (once per
    change) + tick (every loop, non-blocking) split, driving the Alarmed
    pulse and Recovering fade off millis(). Buzzer driver uses distinct
    on/off beep patterns per state instead of tones, since this buzzer has
    no signal pin and can't vary pitch. All 6 states confirmed visually
    and audibly.
    [buzzer_driver.cpp, main.cpp]
2026-09-17 Phase 5: state machine, non-overlapping-window classification fix
    Implements the PRD's NORMAL/DIZZY/ALARMED/RECOVERING state machine
    using string comparison against modelLabel() rather than hardcoded
    class indices. Fixes a false-alarm bug: continuous sliding-window
    classification (~50Hz) compounded the model's small non-fall->fall
    misclassification rate into frequent spurious alarms; reverted to a
    fresh non-overlapping window per classification (~0.67/sec), matching
    how the model was actually validated.
    By explicit choice, ALARMED->RECOVERING now accepts stand/dizzy/walk
    (not the PRD's original stand/sit) as signs of recovery. Live debug
    testing found this interacts with the model's real be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
    [main.cpp]
2026-09-17 Phase 5 complete: Telegram integration
    Implements sendTelegramMessage() as an HTTPS GET to the Bot API
    (WiFiClientSecure + HTTPClient), non-blocking WiFi check so a down
    connection means "skip this cycle" rather than a stalled loop. Returns
    success/failure so the state machine retries the fall alert
    automatically instead of marking it sent unconditionally. Confirmed
    end-to-end: a simulated fall produces a real Telegram message.
    Adds include/secrets.h.example as the committed template (real
    secrets.h stays git-ignored). The chat ID had to be fetched properly
    via the Bot API -- the Phase 1 .env notes had saved the lookup URL,
    not the actual numeric ID.
    [main.cpp]
2026-09-17 Phase 6: async Telegram task, fall-confirmation redesign, WiFi/reliability fixes
    Root cause of "stuck" states and multi-second alert delays: the Telegram
    HTTPS send was blocking the main sensor/classification loop directly.
    Moved all Telegram sending onto its own FreeRTOS task, pinned to core 0,
    so a slow or retrying send can never stall IMU sampling or classification.
    Also fixes found and fixed during live hardware/field testing:
    - Fall confirmation redesigned around a fixed debounce that always alerts,
    never conditionally on recovery (an earlier 20s wait-and-decide design
    was built, tested, and rejected as too risky)
    - Sticky ALARMED->RECOVERING bug (excluded "sit") broadened to any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
    [buzzer_driver.cpp, main.cpp]
